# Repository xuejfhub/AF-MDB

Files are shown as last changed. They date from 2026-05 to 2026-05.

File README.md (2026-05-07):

# AF-MDB

AF-MDB (AF Motor Development Board) 是一个基于 STM32H7 的 PMSM/BLDC 电机控制开发板与对拖实验平台，包含硬件原理图、STM32 固件、MATLAB/Simulink 仿真模型和由 Simulink Embedded Coder 生成的 FOC 算法代码。

## 项目图览

<table>
	<tr>
		<td align="center" width="50%">
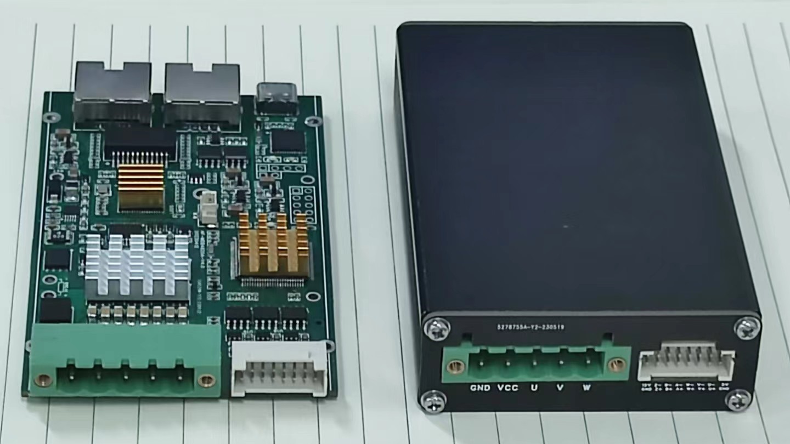
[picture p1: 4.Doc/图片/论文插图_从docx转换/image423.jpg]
驱动器实物照片
			<br>
			<strong>驱动器实物</strong>
		</td>
		<td align="center" width="50%">
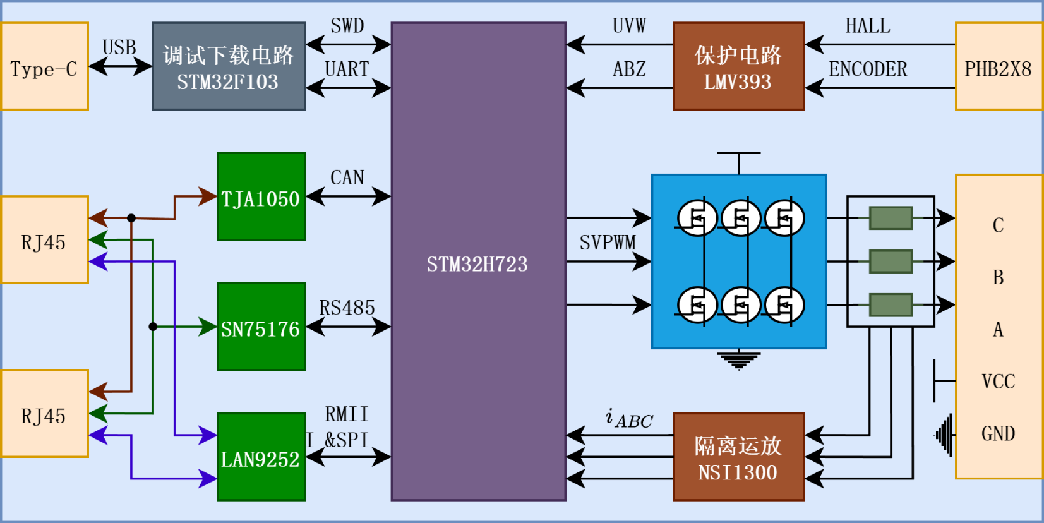
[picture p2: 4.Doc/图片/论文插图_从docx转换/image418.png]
驱动器硬件框图
			<br>
			<strong>硬件设计框图</strong>
		</td>
	</tr>
	<tr>
		<td align="center" width="50%">
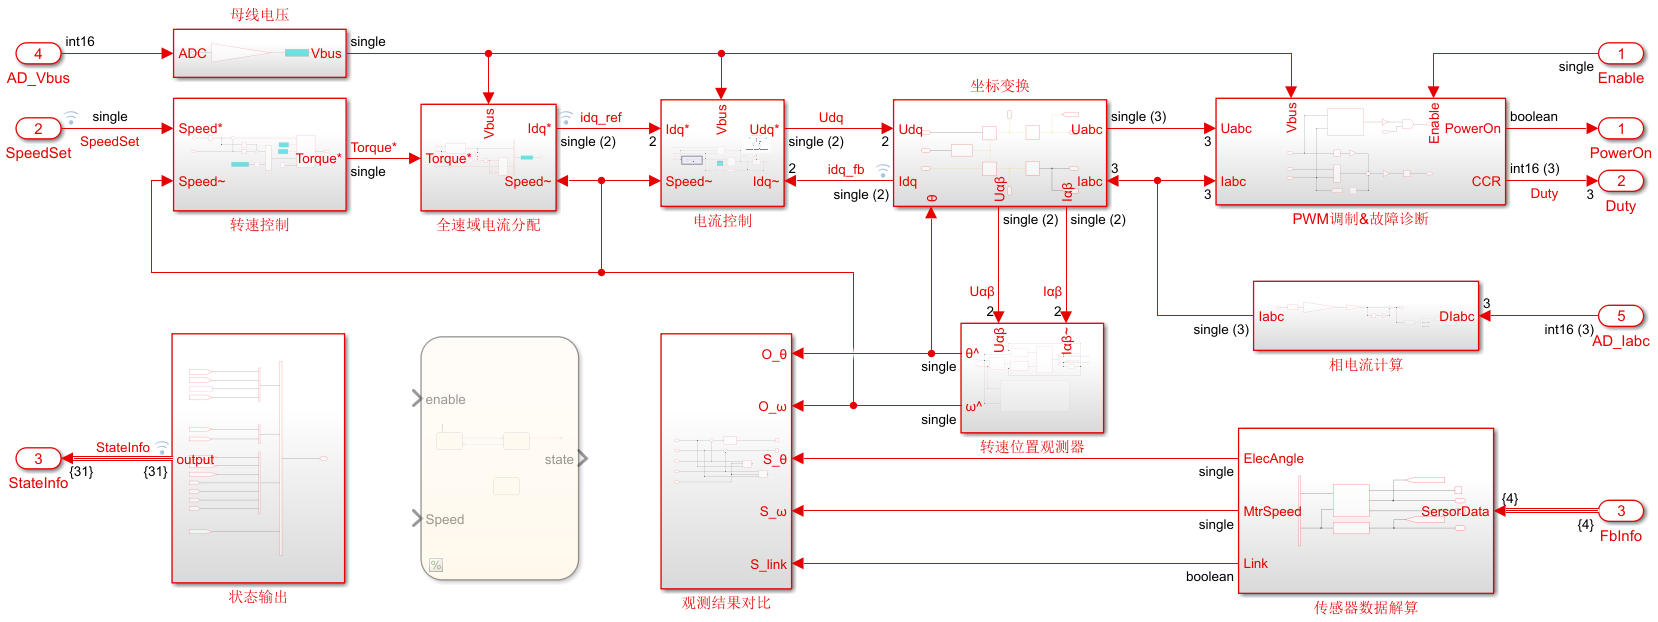
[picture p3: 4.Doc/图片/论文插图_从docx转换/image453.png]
无位置传感器 FOC 控制仿真设计图
			<br>
			<strong>Simulink 控制仿真图</strong>
		</td>
		<td align="center" width="50%">
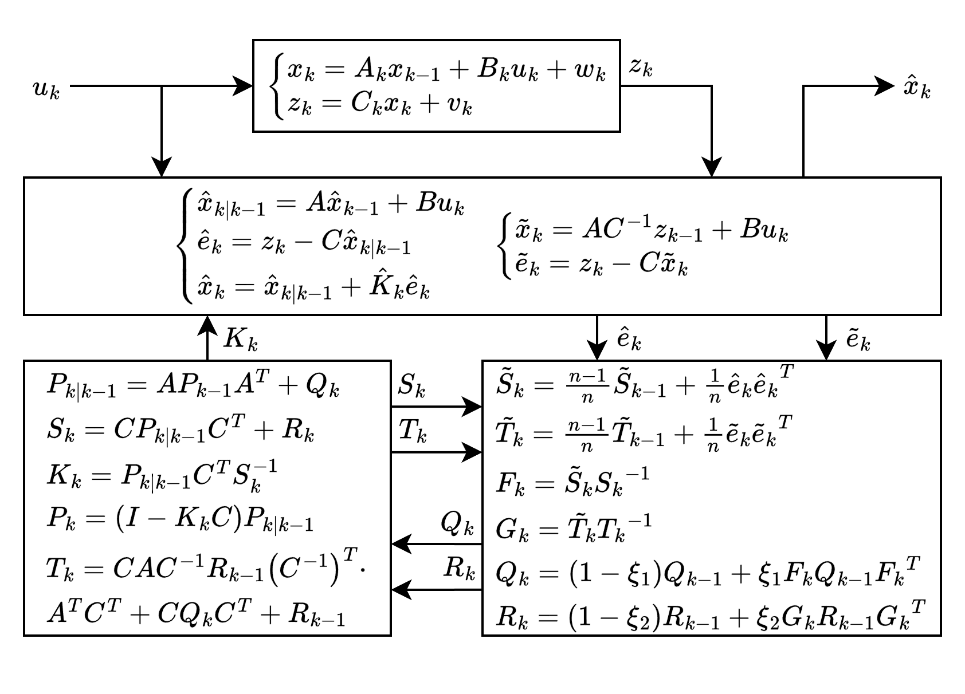
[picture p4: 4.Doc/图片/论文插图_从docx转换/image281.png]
自适应卡尔曼观测器
			<br>
			<strong>自适应卡尔曼观测器</strong>
		</td>
	</tr>
	<tr>
		<td align="center" width="50%">
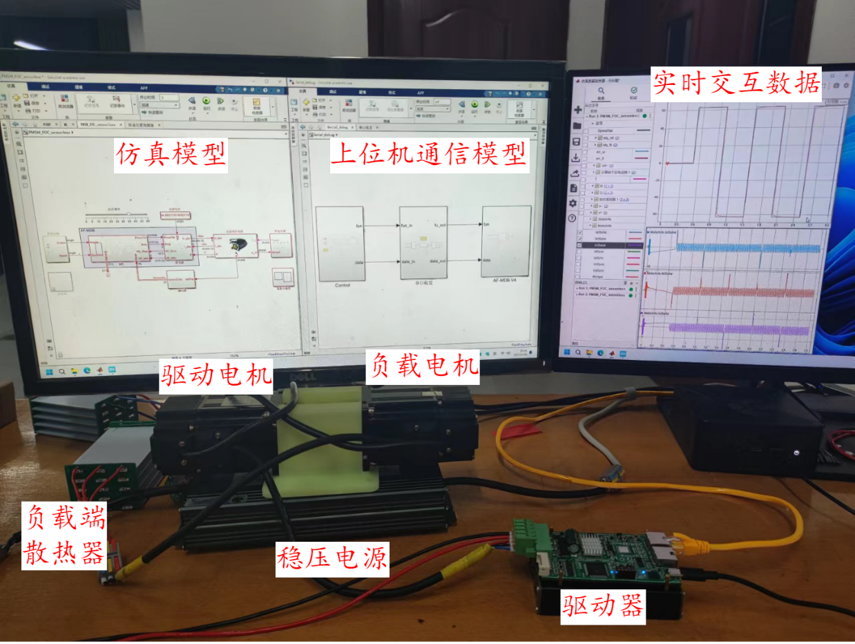
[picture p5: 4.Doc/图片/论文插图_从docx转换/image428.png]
双电机对拖联调平台
			<br>
			<strong>双电机对拖联调平台</strong>
		</td>
		<td align="center" width="50%">
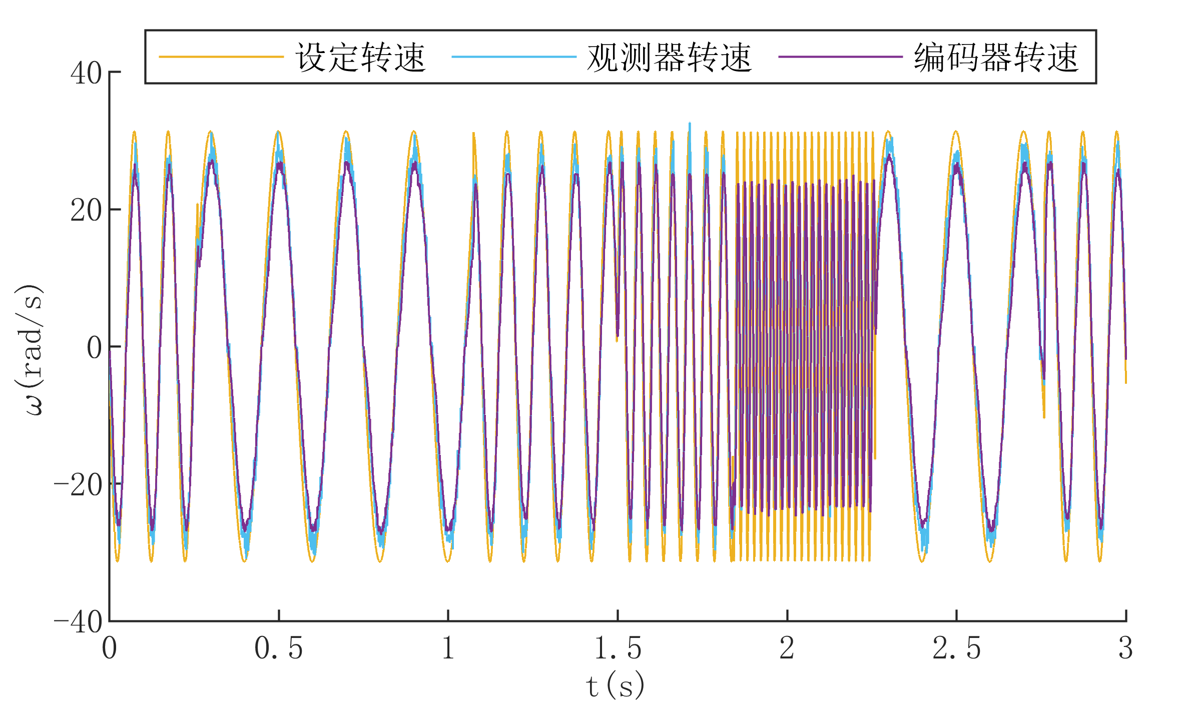
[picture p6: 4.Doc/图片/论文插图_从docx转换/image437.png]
实物转速动态跟踪曲线
			<br>
			<strong>实物转速动态跟踪曲线</strong>
		</td>
	</tr>
</table>

## 算法与实验亮点

AF-MDB 的核心目标是在不使用位置传感器、尽量避免高频注入噪声的情况下，实现 PMSM 全速度范围控制。项目中的两个关键思路是：

- **FAKF 快速自适应卡尔曼观测器**：先由电压、电流计算反电动势，再从反电动势提取带噪声的速度和角度测量值，最后用低阶线性卡尔曼观测器融合机械模型。相比直接对 PMSM 非线性模型做 EKF，FAKF 降低了矩阵运算量，并通过残差、息差自适应调整 `Q/R` 噪声协方差。
- **OAPT 最优电流点跟踪**：把低速角度稳定、d 轴电流损耗和高速电压余量合成为性能指标 $J(i_d, \omega_m, U_{dc})$，在线跟踪 $i_d^{\ast}=\arg\min J$。低速时用正向 d 轴电流帮助角度收敛，高速或欠压时转入弱磁，减少高频注入和策略切换。

实物实验在双电机对拖平台上完成，结果表明：从 5% 额定转速加速到 95% 额定转速用时小于 0.03 s，额定转速下速度波动小于 1%，转速环带宽可达 50 Hz；相比高频注入法，实验中运行噪声降低约 1.86 dB；在 STM32H723 上 FAKF 算法耗时约 28.3 us，比传统 EKF 少约 16.4 us。

## 仓库内容

- `1.Hardware/`：硬件说明、引脚映射、各版本原理图导出文件和必要设计资料。完整在线原理图、PCB 和硬件工程以 OSHWHub 页面为准。
- `2.Software/`：STM32CubeIDE 固件工程。当前主线工程为 `MDB-V4.1`，可直接使用仓库内的 `3.Simulation/FOC_ert_rtw/` 编译，不需要重新生成 Simulink 代码。
- `3.Simulation/`：MATLAB/Simulink 模型、参数脚本、电机参数和驱动参数。主要仿真模型为 `model/Simulation/PMSM_FOC_sensorless.slx`，`model/Simulation/ModelRef/FOC.slx` 用作固件算法引用模型和代码生成入口。
- `4.Doc/`：项目说明、设计文档和研究资料。

## 推荐环境

- STM32CubeIDE 1.19.0：用于导入、配置和编译 `2.Software/MDB-V4.1`。
- STM32CubeMX：随 CubeIDE 使用，用于生成底层外设驱动初始化代码。
- MATLAB/Simulink R2026a：用于打开仿真模型、运行参数脚本，并通过 Embedded Coder 重新生成算法 C 代码。

## 开源范围

当前公开仓库以已发布和可复现的历史版本资料为主。硬件与软件的 V5.0 目录属于本地私有开发资料，不纳入 GitHub 公开仓库；其他版本资料按 `.gitignore` 过滤编译产物、制造输出和本地备份后可推送到云端。

## 快速开始

### 查看硬件

打开 OSHWHub 项目页查看完整硬件工程：

<https://oshwhub.com/xue_jingfei/af-mdb>

Git 仓库中的硬件资料主要用于快速查看原理图、理解接口定义，并与软件和仿真工程对应。若需要打样或修改 PCB，请优先以 OSHWHub 上的最新版工程文件为准。

### 编译固件

1. 安装 STM32CubeIDE 1.19.0。
2. 用 STM32CubeIDE 导入 `2.Software/MDB-V4.1`。
3. 执行 Build Project。

CubeMX 负责底层外设驱动配置和初始化代码生成，FOC 算法代码由 Simulink Embedded Coder 生成。仓库会保留 `3.Simulation/FOC_ert_rtw/`，因此只想编译固件的用户不需要安装 MATLAB/Simulink。若修改 `3.Simulation/model/Simulation/ModelRef/FOC.slx`，则需要重新生成该目录后再编译固件。

### 运行仿真

1. 使用 MATLAB 打开 `3.Simulation/AFMCS.prj`。
2. 运行 `3.Simulation/code/ParameterInit.mlx` 初始化参数。
3. 打开 `3.Simulation/model/Simulation/PMSM_FOC_sensorless.slx` 运行主要控制仿真。
4. 如需重新生成固件算法代码，打开 `3.Simulation/model/Simulation/ModelRef/FOC.slx` 并生成 `FOC_ert_rtw/`。

## 算法说明

`MDB-V4.1` 是当前推荐的主线固件工程。算法模型采用独立引用模型 `3.Simulation/model/Simulation/ModelRef/FOC.slx`，接口和数据类型已按嵌入式代码生成流程配置完成，可直接使用 Embedded Coder 生成 C 语言代码。固件工程直接引用 `3.Simulation/FOC_ert_rtw/` 中的生成代码，并在应用层完成 ADC、编码器、Hall、上位机命令和 PWM 输出之间的适配。

Simulink 算法模型包含作者改进的快速自适应卡尔曼观测器算法和最优电流点跟踪策略，用于 PMSM 全速度范围无传感器控制。建议先阅读 [4.Doc/永磁同步电机低噪声全速度范围无传感器控制研究.md](4.Doc/永磁同步电机低噪声全速度范围无传感器控制研究.md) 了解项目相关的核心思想；完整算法原理、推导和实验结果请查阅论文《永磁同步电机低噪声全速度范围无传感器控制研究》。

## 安全说明

本项目涉及电机驱动、功率电子、电流采样和高速 PWM 控制。复现前请确认供电电压、电流限制、母线电容耐压、过流/过压/欠压保护、散热和急停措施。首次上电建议使用限流电源，并在接入电机前验证采样零点、PWM 死区和保护逻辑。

## 引用

本项目的控制算法来自论文《永磁同步电机低噪声全速度范围无传感器控制研究》。精简版见 [4.Doc/永磁同步电机低噪声全速度范围无传感器控制研究.md](4.Doc/永磁同步电机低噪声全速度范围无传感器控制研究.md)。

如果本项目对你的研究或开发有帮助，可以参考原论文：

> 《永磁同步电机低噪声全速度范围无传感器控制研究》
> DOI: `10.27759/d.cnki.ggxgx.2024.000640`

完整硬件开源页面：<https://oshwhub.com/xue_jingfei/af-mdb>

## 许可证

请以仓库根目录 `LICENSE` 文件和 OSHWHub 项目页面标注为准。若当前副本未包含明确许可证，请在复用或再发布前联系作者确认授权范围。

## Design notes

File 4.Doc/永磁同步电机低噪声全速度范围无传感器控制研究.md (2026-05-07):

# 永磁同步电机低噪声全速度范围无传感器控制研究：项目技术速览

> 本文档是面向 AF-MDB 项目读者整理的技术说明，重点保留第 3、4、5 章中与项目实现相关的创新思想、核心公式、框图和实验结论。
>
> 原论文中的封面、声明、目录、学校培养信息、绪论综述、参考文献和致谢已删去。完整理论推导、公式编号、文献来源和实验细节请查阅原论文《永磁同步电机低噪声全速度范围无传感器控制研究》，DOI: `10.27759/d.cnki.ggxgx.2024.000640`。

## 阅读线索

这份速览不再按论文格式展开，而是按项目读者最关心的顺序组织：

1. 先理解 PMSM 无传感器控制为什么难：低速反电动势弱、高速电压受限、高频注入有噪声。
2. 再看第 3 章的 FAKF：如何把传统 EKF 拆成“非线性测量提取 + 低阶线性卡尔曼观测”。
3. 再看第 4 章的 OAPT：如何用 d 轴电流同时处理低速稳定、高速弱磁和电池欠压。
4. 最后看第 5 章的工程验证：硬件、软件、联调平台、实物转速跟踪、噪声和运行时间。

## 项目要解决的问题

PMSM 无传感器控制希望不依赖编码器或位置传感器，直接通过电压、电流和电机模型估计转子位置与转速，再完成 FOC 闭环控制。这样可以降低成本、减少线束、提升系统可靠性，但工程上会遇到几个矛盾：

- **低速和零速难**：反电动势幅值随转速下降而变小，模型观测器很难得到可靠角度。
- **高速电压受限**：转速升高后反电动势增大，母线电压不足时 q 轴电压余量变小，转矩能力下降。
- **高频注入有噪声**：传统全速域方案常在低速使用高频注入，中高速切换到观测器法，但高频电压会带来明显电磁声。
- **切换策略复杂**：两种估计方法之间需要融合、切换或权重调度，边界稳定性和参数调试都比较麻烦。
- **嵌入式算力有限**：20 kHz 控制频率下单周期只有 50 us 左右，ADC、观测器、FOC 和 PWM 更新都要在一个周期内完成。

AF-MDB 的算法主线可以概括为：**用快速自适应卡尔曼观测器 FAKF 提高位置/速度估计质量，用最优电流点跟踪 OAPT 改善观测器在零低速和弱磁区的工作条件，从而减少对高频注入和多策略切换的依赖。**

## 第 3 章：FAKF 快速自适应卡尔曼观测器

### 创新思想

传统 EKF 通常直接对 PMSM 的非线性状态方程做局部线性化，状态维度高，雅可比矩阵复杂，实时运行成本较高，而且过程噪声 `Q`、测量噪声 `R` 对调参非常敏感。

FAKF 的关键改动是把非线性环节和卡尔曼滤波环节分开：

1. 先由采样电压、电流计算反电动势。
2. 再由反电动势提取带噪声的角度和速度测量值。
3. 最后只对速度、角度构成的低阶线性系统做卡尔曼融合。
4. 用残差和息差在线估计噪声协方差，使 `Q`、`R` 能随工况变化自适应调整。

### 非线性测量提取

在静止坐标系下，可先由电压方程提取反电动势。工程离散形式可以理解为：

$$
\begin{aligned}
e_{\alpha}(k) &= u_{\alpha}(k) - R_s i_{\alpha}(k) - L_s \frac{i_{\alpha}(k)-i_{\alpha}(k-1)}{T_s} \\
e_{\beta}(k) &= u_{\beta}(k) - R_s i_{\beta}(k) - L_s \frac{i_{\beta}(k)-i_{\beta}(k-1)}{T_s}
\end{aligned}
$$

对表贴式 PMSM，反电动势与电角度、转速近似满足：

$$
\begin{aligned}
e_{\alpha} &= -\omega_e \psi_f \sin\theta_e \\
e_{\beta} &= \omega_e \psi_f \cos\theta_e
\end{aligned}
$$

因此可以从反电动势中得到测量角度和速度：

$$
\begin{aligned}
θ_{e,z} &= \operatorname{atan2}(-e_{\alpha}, e_{\beta}) \\
|\omega_{e,z}| &= \frac{\sqrt{e_{\alpha}^{2}+e_{\beta}^{2}}}{\psi_f}
\end{aligned}
$$

由于反电动势在低速时很弱，这一步得到的是“带噪声的测量值”，不是最终估计值。FAKF 的作用就是把这些测量值和机械运动模型融合起来。

电磁转矩作为观测器输入，常用表达为：

$$
T_e = 1.5p\left[\psi_f i_q + (L_d-L_q)i_d i_q\right]
$$

对于表贴式 PMSM，`L_d` 与 `L_q` 接近，上式常简化为：

$$
T_e \approx 1.5p\psi_f i_q
$$

### 低阶线性观测器

FAKF 只把机械速度和电角度作为核心状态：

$$
\begin{aligned}
x_k &= [\omega_m,\ \theta_e]^T \\
u_k &= T_e \\
z_k &= [\omega_{m,z},\ \theta_{e,z}]^T
\end{aligned}
$$

离散机械模型可写成线性状态空间形式：

$$
\begin{aligned}
x_k &= A x_{k-1} + B u_k + w_k \\
z_k &= H x_k + v_k
\end{aligned}
$$

其中 `w_k` 是过程噪声，主要吸收负载扰动、模型不准和未建模动态；`v_k` 是测量噪声，主要来自反电动势提取、电流采样和数值微分。相比传统 4 阶非线性 EKF，这个观测器的矩阵维度更小，状态转移矩阵更简单，更适合放进 STM32H7 的高速控制周期。

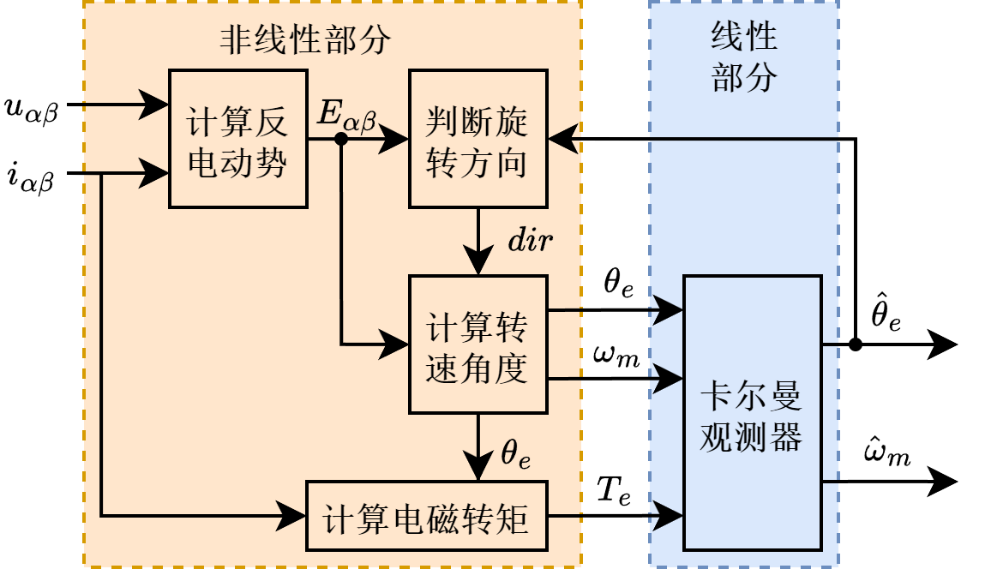
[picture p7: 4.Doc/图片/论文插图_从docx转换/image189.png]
FAKF 观测器结构


### 卡尔曼更新过程

FAKF 的滤波核心仍然遵循标准离散卡尔曼预测与校正：

$$
\begin{aligned}
x_k^- &= A x_{k-1} + B u_k \\
P_k^- &= A P_{k-1} A^T + Q_k \\
K_k &= P_k^- H^T\left(H P_k^- H^T + R_k\right)^{-1} \\
x_k &= x_k^- + K_k\left(z_k - Hx_k^-\right) \\
P_k &= \left(I-K_kH\right)P_k^-
\end{aligned}
$$

这里 `K_k` 是卡尔曼增益，`P_k` 是估计协方差。传统 EKF 的难点在于 `Q`、`R` 难以固定整定：转速、采样噪声、负载扰动变化后，原先好用的噪声矩阵可能变得不匹配。

### Q/R 自适应思想

论文中引入两个误差信号：

$$
\begin{aligned}
r_k &= z_k - Hx_k^- \\
d_k &= z_k - z_k^-
\end{aligned}
$$

其中 $r_k$ 为残差，表示测量值与当前预测值之间的偏差；$d_k$ 为息差，表示新的测量值与基于上一时刻信息预测测量值之间的偏差。

然后在线估计残差和息差的协方差：

$$
\begin{aligned}
C_r(k) &= \operatorname{cov}(r_k) \\
C_d(k) &= \operatorname{cov}(d_k)
\end{aligned}
$$

直觉上：

- 残差的统计强度反映“测量噪声和预测不一致”的程度。
- 息差的统计强度可以帮助区分过程噪声和测量噪声。
- 当估计协方差与理论协方差不匹配时，说明当前 `Q_k` 或 `R_k` 需要调整。

为了避免直接做矩阵减法导致协方差矩阵失去正定性，论文采用合同变换思想修正 `Q`、`R`。工程上可以理解为：

$$
\begin{aligned}
Q_{k+1} &= \operatorname{adapt}\left(Q_k, C_d, C_{d,\mathrm{theory}}\right) \\
R_{k+1} &= \operatorname{adapt}\left(R_k, C_r, C_{r,\mathrm{theory}}\right)
\end{aligned}
$$

其中自适应律带有收敛系数，用来控制噪声矩阵调整速度。这样 FAKF 不必长期依赖一组固定噪声参数，能够随转速变化、扰动和采样噪声变化调整滤波权重。

自适应卡尔曼观测器信号流

### 最终效果

FAKF 的效果主要体现在三点：

- 在全速阶跃、低速突加负载、高速突加负载、正弦加减速等仿真中，速度和角度能较好跟随真实值。
- 与传统 EKF 相比，FAKF 避免了高阶非线性矩阵运算，降低了实时计算成本。
- 自适应噪声矩阵使观测器在不同转速段能保持更稳定的误差特性。

## 第 4 章：OAPT 最优电流点跟踪

### 创新思想

FAKF 虽然降低了 EKF 的计算量并提高了中高速观测质量，但接近零速时反电动势仍然趋近于零，仅靠反电动势观测很容易角度不收敛。传统办法是低速高频注入，中高速观测器法，再做切换。OAPT 的思路不同：**它不额外估计角度，而是通过 d 轴电流改变电机工作点，让同一个观测器在零低速、高速和欠压时都更容易工作。**

### d 轴电流的三个作用

在表贴式 PMSM 中，d 轴电流几乎不产生主要转矩，但它会影响三个关键指标：

1. **角度稳定性**：低速时正向 d 轴电流能让角度误差形成更有利的负反馈。
2. **效率与发热**：d 轴电流越大，铜损和无功功率越大。
3. **电压余量**：高速或欠压时负向 d 轴电流可弱磁，降低反电动势，为 q 轴控制保留电压空间。

在论文采用的符号约定下，角度误差 $\Delta\theta$ 存在时，d 轴电流会产生一个与误差相关的转矩项，可概括为：

$$
T_d \approx 1.5p\psi_f i_d \sin(\Delta\theta)
$$

当 `i_d` 的方向选择合适时，这个转矩项会帮助角度误差收敛；方向相反时，可能形成正反馈并放大误差。这也是 OAPT 在低速选择正向 d 轴电流的核心原因。

### 综合性能指标

OAPT 将“低速稳定、效率、高速电压余量”统一成一个性能指标函数。工程理解可写为：

$$
J(i_d, \omega_m, U_{dc}) = L J_{\mathrm{stable}} + M J_{\mathrm{loss}} + N J_{\mathrm{voltage}}
$$

其中：

- `J_stable` 描述低速角度稳定性需求。
- `J_loss` 描述 d 轴电流带来的发热和无功功率损失。
- `J_voltage` 描述高速或欠压时的电压余量。
- `L`、`M`、`N` 是权重，可根据应用偏向低速稳定、效率或高速性能。

最终控制目标是找到当前转速和母线电压下的最优 d 轴电流：

$$
i_d^{\ast} = \arg\min_{i_d} J(i_d, \omega_m, U_{dc})
$$

论文没有把这个问题做成重计算量的解析求解，而是使用梯度下降思想在线跟踪最优点：

$$
\frac{\partial J}{\partial i_d} \approx \frac{J(i_d + \Delta i, \omega_m, U_{dc}) - J(i_d, \omega_m, U_{dc})}{\Delta i}
$$

$$
i_d^{\ast}(k+1)=\operatorname{sat}\left[i_d^{\ast}(k)-\eta\frac{\partial J}{\partial i_d}\right]
$$

`eta` 是学习率，`sat[]` 用来限制电流范围。这样算法可以在控制周期内轻量运行，不需要复杂求导或查大表。

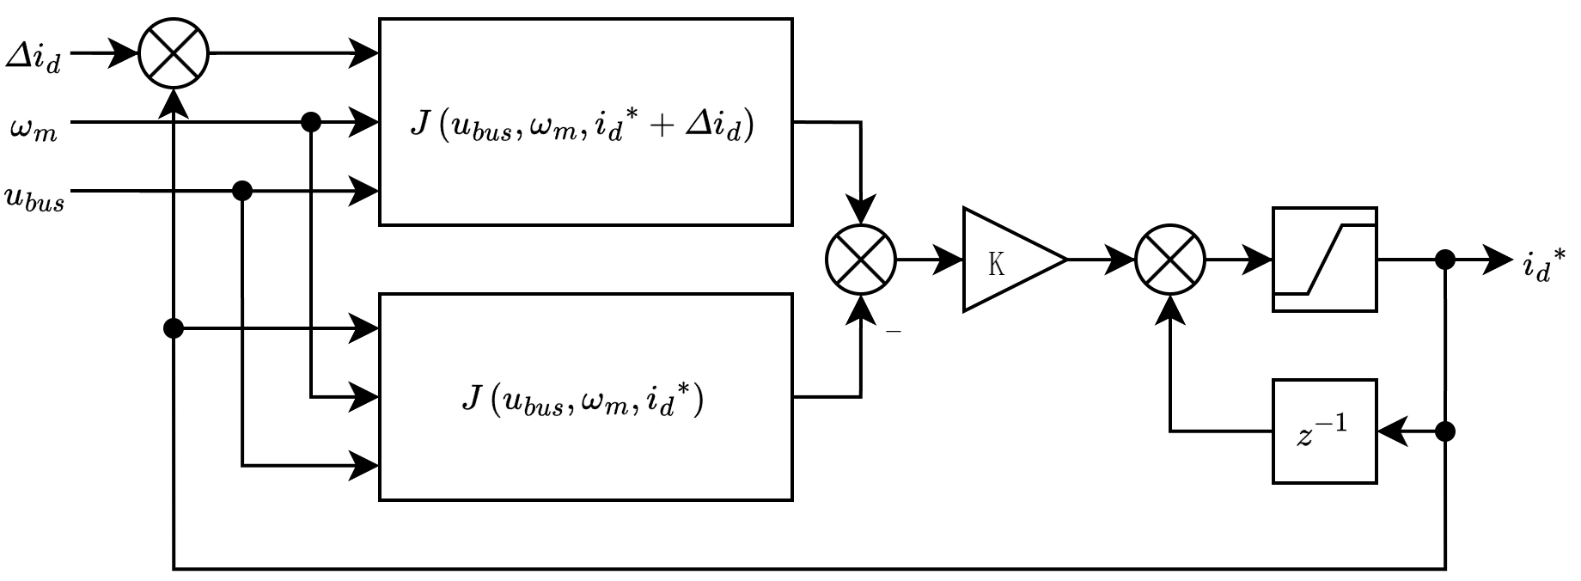
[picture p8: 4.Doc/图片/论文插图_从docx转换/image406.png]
最优电流点跟踪框图


### FAKF + OAPT 的组合方式

FAKF 和 OAPT 位于控制系统的不同位置：

- FAKF 负责估计转速和角度。
- OAPT 负责给出当前工况下更合适的 d 轴电流目标。
- 两者同时工作，不需要像“高频注入 + 观测器法”那样设计切换边界。

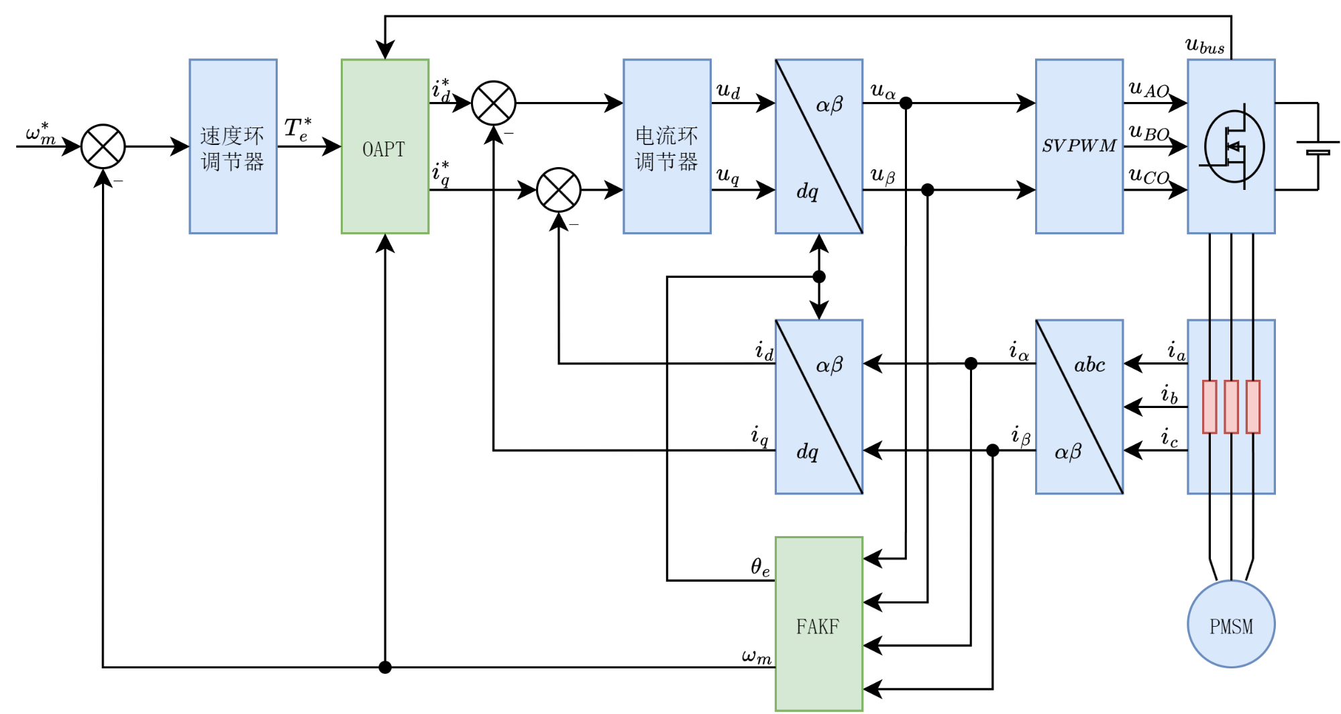
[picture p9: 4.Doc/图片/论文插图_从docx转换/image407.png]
FAKF 与 OAPT 结合后的全速度范围控制结构


### 最终效果

OAPT 的意义不是单纯“弱磁”，而是把低速启动、高速弱磁和欠压补偿放到同一套电流分配逻辑里：

- 零低速时通过正向 d 轴电流改善角度收敛，减少启动反转。
- 中速时尽量减小无效 d 轴电流，兼顾效率。
- 高速或母线电压不足时自动偏向弱磁，保证 q 轴电压余量。
- 不使用高频注入，因此可避免高频注入带来的尖锐运行噪声。

## 第 5 章：实验平台与实物验证

### 硬件平台

论文实验平台围绕 STM32H7 系列主控设计，硬件包含电源保护与 DCDC、MCU 最小系统、下载调试、三相逆变器、电流采样、编码器/Hall 接口和通信接口等模块。驱动器参数包括 20 kHz 控制频率、ADC 采样、电流采样和 PWM 死区配置等，目标是让算法能在真实功率驱动条件下闭环运行。

驱动器硬件设计方案

驱动器实物照片

### 软件与仿真

软件按层次划分为底层驱动、算法层和应用层。Simulink/Embedded Coder 负责生成 FOC、FAKF、OAPT 等算法代码；STM32CubeIDE 工程负责外设初始化、中断调度、ADC/PWM/通信和保护逻辑。

无位置传感器 FOC 控制仿真设计图

### 实物联调平台

实验采用双电机对拖平台：一台电机作为被控电机，另一台电机作为负载电机，通过负载电阻模拟风机、泵类负载特性。这样可以验证算法在带载、正反转、低速、高速和动态变速下的实际表现。

双电机对拖实验平台

### 实物实验结果

论文中重点验证了四类结果：

| 测试项目 | 结果摘要 |
| --- | --- |
| 高低速正反转带载 | 从 5% 额定转速加速到 95% 额定转速，用时小于 0.03 s；稳态速度误差小于 1%。 |
| 动态转速跟踪 | 50 Hz 转速激励下仍能稳定跟随，角度误差保持在可收敛范围内。 |
| 运行噪声 | 相比高频注入法，实验中运行噪声平均降低约 1.86 dB。 |
| 算法耗时 | STM32H723 上 FAKF 总耗时约 28.3 us，传统 EKF 约 44.7 us，减少约 16.4 us。 |

实物转速动态跟踪曲线

### 工程结论

综合仿真和实物实验，FAKF + OAPT 的价值主要是：

1. 在不使用位置传感器的情况下覆盖零速、低速、中高速、正反转和带载工况。
2. 用 OAPT 替代高频注入的低速稳定作用，降低运行噪声。
3. 用低阶观测器和自适应噪声矩阵降低 EKF 的计算压力和调参压力。
4. 在 STM32H7 + 20 kHz 控制频率下保留实时裕度，便于工程移植。

## 与 AF-MDB 仓库的关系

| 目标 | 路径 | 说明 |
| --- | --- | --- |
| 固件工程 | `2.Software/MDB-V4.1/` | 当前推荐的 STM32CubeIDE 主线工程。 |
| 仿真工程 | `3.Simulation/AFMCS.prj` | MATLAB 项目入口。 |
| 控制仿真 | `3.Simulation/model/Simulation/PMSM_FOC_sensorless.slx` | PMSM 无传感器 FOC 仿真模型。 |
| 代码生成入口 | `3.Simulation/model/Simulation/ModelRef/FOC.slx` | 用于 Embedded Coder 生成嵌入式算法代码。 |
| 生成代码 | `3.Simulation/FOC_ert_rtw/` | 固件工程直接引用的算法 C 代码。 |
| 硬件资料 | `1.Hardware/` | 原理图导出、引脚映射和历史版本硬件资料。 |

如果你想复现或继续开发，建议先从 `3.Simulation/model/Simulation/ModelRef/FOC.slx` 和 `3.Simulation/model/Simulation/PMSM_FOC_sensorless.slx` 理解算法，再看 `2.Software/MDB-V4.1/` 中如何把生成代码接入 ADC、PWM、编码器、Hall 和通信任务。

## 适用边界与注意事项

- OAPT 会在低速阶段引入 d 轴电流来换取角度稳定性，因此效率不是唯一目标；若目标是极限低功耗，需要重新调整性能指标权重。
- 文档中的公式采用工程化表达，省略了论文中的部分符号定义、严格推导和稳定性证明；完整推导请查阅原论文。
- 实物结果与电机参数、母线电压、电流采样噪声、控制频率、机械负载和保护策略有关，移植到其他电机前需要重新整定和验证。
- 本项目涉及功率电子和高速电机控制，首次上电必须限流，并确认采样零点、PWM 死区、保护阈值和急停措施。

## 引用

如果这份项目资料或算法思路对你的研究和开发有帮助，可以引用原论文：

> 《永磁同步电机低噪声全速度范围无传感器控制研究》
> DOI: `10.27759/d.cnki.ggxgx.2024.000640`

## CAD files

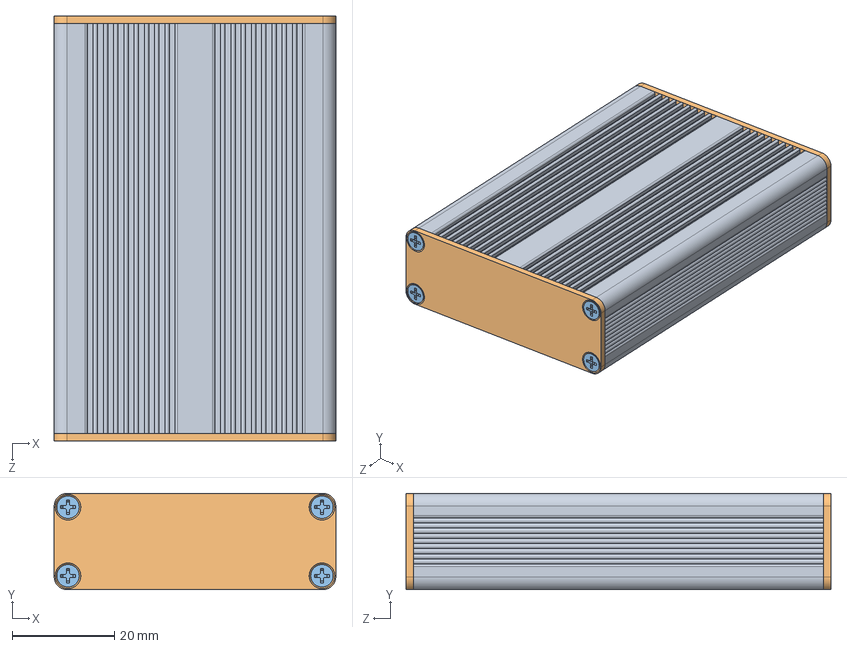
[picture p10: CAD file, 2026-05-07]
1.Hardware/外壳3D文件/V3外壳(J03-55-19)/YG-J03A-0000-000.step
55.0 x 18.8 x 83.0 mm
YG-J03A-0000-001
YG-J03A-0000-002 x 2
GB-T-819.1-2000-C-NI-M2.5X6 x 8

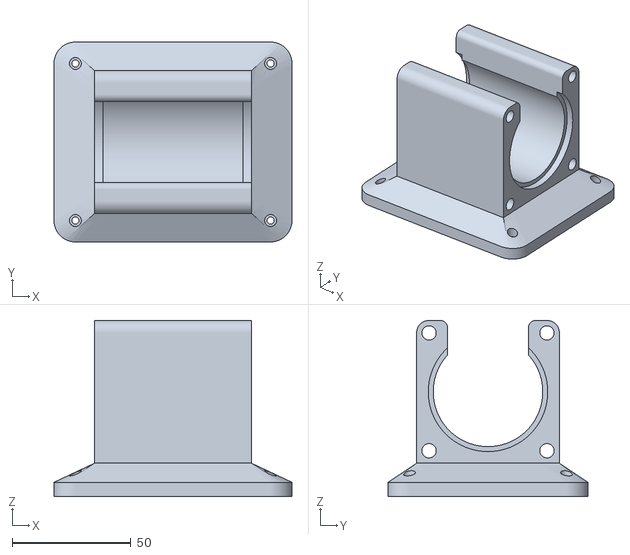
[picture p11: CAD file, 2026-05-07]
1.Hardware/电机支架/60电机对拖支架-支架.obj
100.0 x 84.0 x 74.0

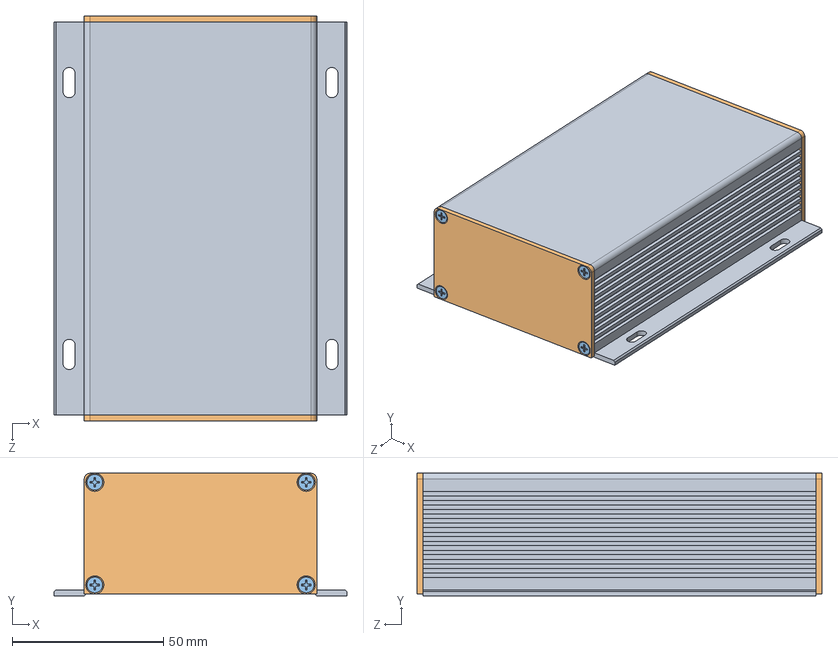
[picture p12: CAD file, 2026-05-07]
1.Hardware/外壳3D文件/V4外壳(J26-97-40.5）/YG-J26A-0000-000.step
97.0 x 40.6 x 134.0 mm
YG-J26A-0000-001
YG-J26A-0000-002 x 2
GB-T-819.1-2000-C-NI-M3X6 x 8

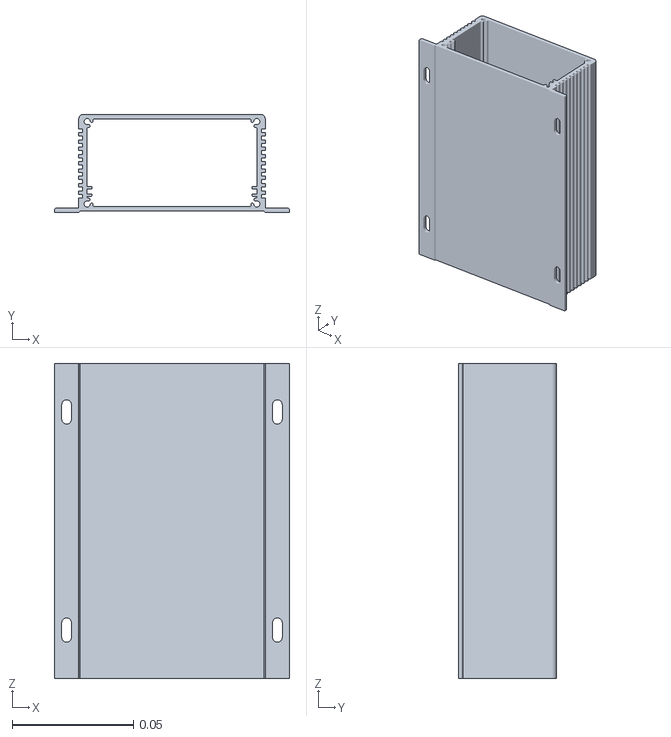
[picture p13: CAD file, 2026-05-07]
1.Hardware/外壳3D文件/V4外壳(J26-97-40.5）/J26-97-40.5-body.obj
0.097 x 0.0406 x 0.13

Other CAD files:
1.Hardware/外壳3D文件/V4外壳(J26-97-40.5）/YG-J26A-0000-001.dwg
1.Hardware/外壳3D文件/V3外壳(J03-55-19)/YG-J03A-0000-002.dwg
1.Hardware/电机支架/60电机对拖支架.FCStd
1.Hardware/外壳3D文件/V3外壳(J03-55-19)/YG-J03A-0000-001.dwg
1.Hardware/外壳3D文件/V4外壳(J26-97-40.5）/YG-J26A-0000-002.dwg
1.Hardware/外壳3D文件/V3外壳(J03-55-19)/YG-J03A-0000-000.dwg
1.Hardware/外壳3D文件/V4外壳(J26-97-40.5）/YG-J26A-0000-000.dwg

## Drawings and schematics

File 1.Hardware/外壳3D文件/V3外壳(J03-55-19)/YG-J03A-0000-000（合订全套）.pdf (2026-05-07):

1

2

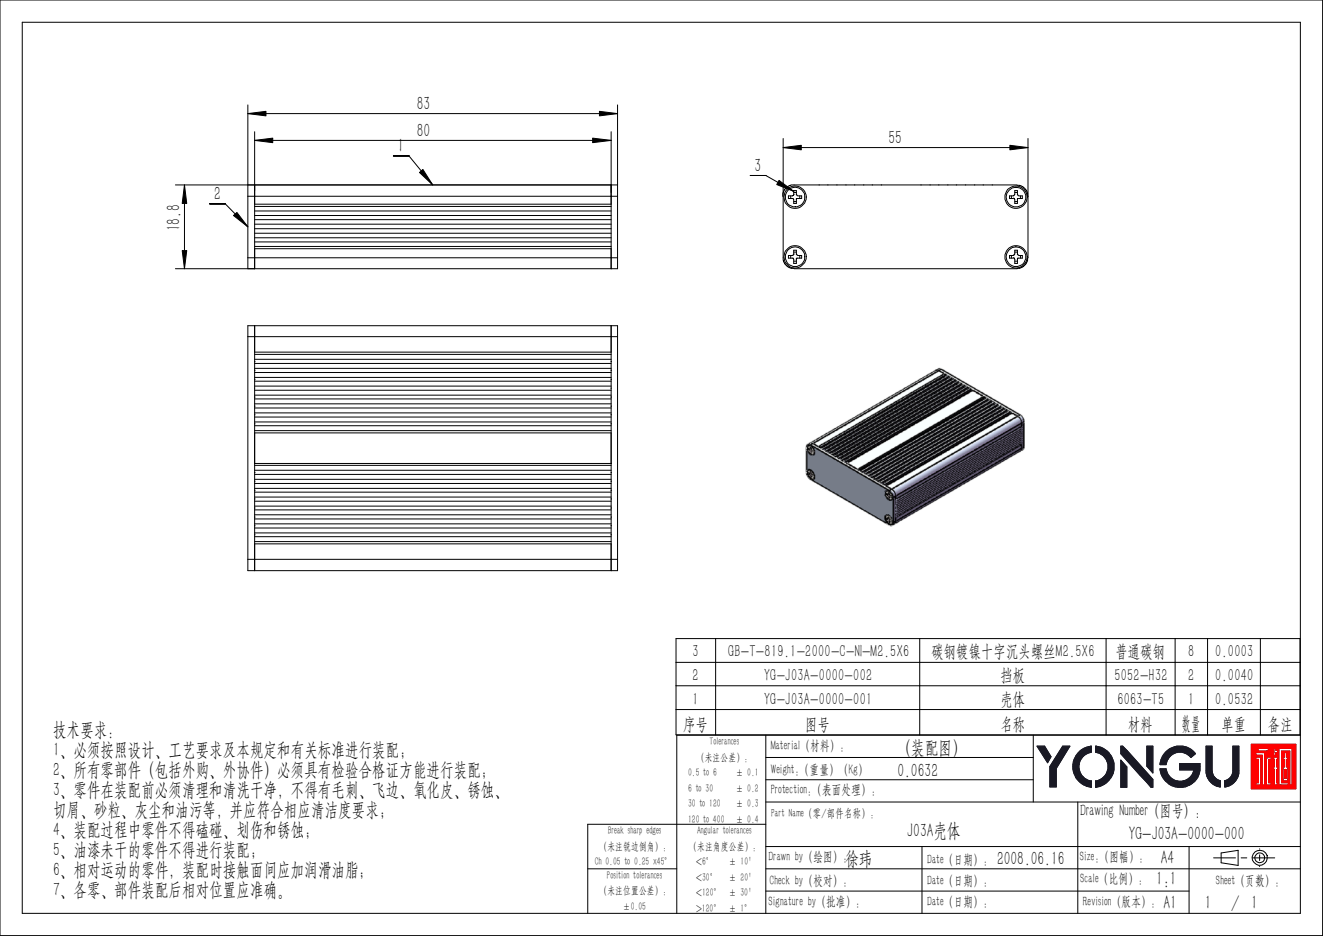
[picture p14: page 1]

3 | GB-T-819.1-2000-C-NI-M2.5X6 | 碳钢镀镍十字沉头螺丝M2.5X6 | 普通碳钢 | 8 | 0.0003
2 | YG-J03A-0000-002 | 挡板 | 5052-H32 | 2 | 0.0040
1 | YG-J03A-0000-001 | 壳体 | 6063-T5 | 1 | 0.0532
序号 | 图号 | 名称 | 材料 | 数量 | 单重 | 备注
Tolerances （未注公差）： 0.5 to 6 ± 0.1 6 to 30 ± 0.2 30 to 120 ± 0.3 120 to 400 ± 0.4 | Material（材料）: （装配图）

技术要求：
1、必须按照设计、工艺要求及本规定和有关标准进行装配；
2、所有零部件（包括外购、外协件）必须具有检验合格证方能进行装配；
3、零件在装配前必须清理和清洗干净，不得有毛刺、飞边、氧化皮、锈蚀、
切屑、砂粒、灰尘和油污等，并应符合相应清洁度要求；
4、装配过程中零件不得磕碰、划伤和锈蚀；
5、油漆未干的零件不得进行装配；
6、相对运动的零件，装配时接触面间应加润滑油脂；
7、各零、部件装配后相对位置应准确。

Weight:（重量）（Kg）
Protection:（表面处理）：

Part Name（零/部件名称）: J03A壳体 | Drawing Number（图号）: YG-J03A-0000-000

Break sharp edges （未注锐边倒角）： Ch 0.05 to 0.25 x45° | Angular tolerances （未注角度公差）： ± 10' <30° ± 20' | Drawn by（绘图）: <6°

徐玮 | 2008.06.16 Date（日期）： | Size:（图幅）： A4

Position tolerances （未注位置公差）： ±0.05 | | Check by（校对）: | Scale（比例）： | Sheet（页数）： /

Signature by（批准）: | A1 Revision（版本）：

A

55

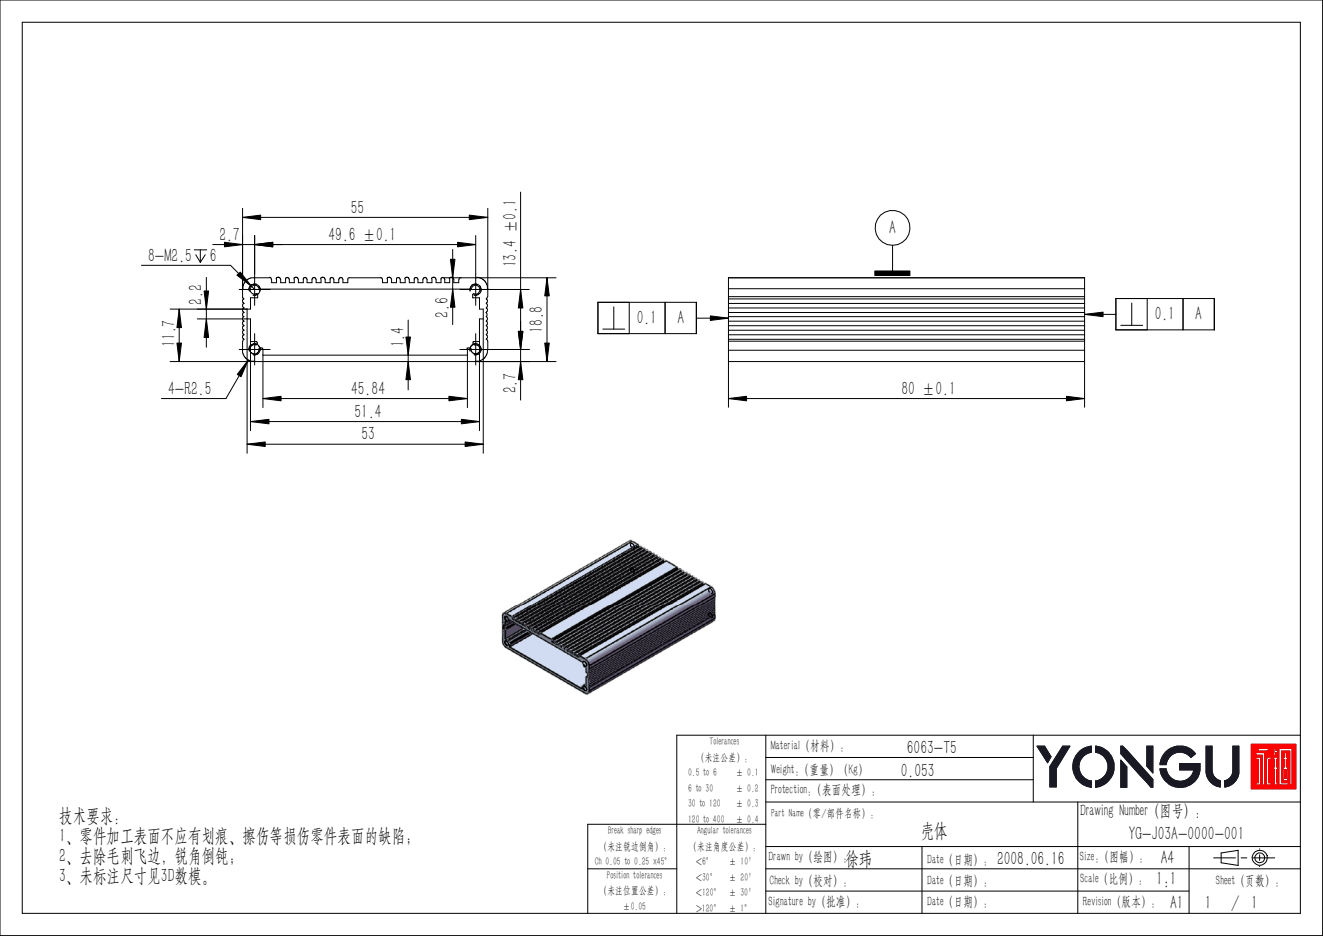
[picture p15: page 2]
Tolerances （未注公差）：; 技术要求： 1、零件加工表面不应有划痕、擦伤等损伤零件表面的缺陷； 2、去除毛刺飞边，锐角倒钝；; 3、未标注尺寸见3D数模。 ¹¹.7

Material（材料）:
Weight:（重量）（Kg）
Protection:（表面处理）：

Part Name（零/部件名称）: 壳体 | Drawing Number（图号）: YG-J03A-0000-001

Break sharp edges （未注锐边倒角）： | Angular tolerances （未注角度公差）： ± 10' | Drawn by（绘图）: <6°

徐玮 | 2008.06.16 | Size:（图幅）： A4

1.5

55

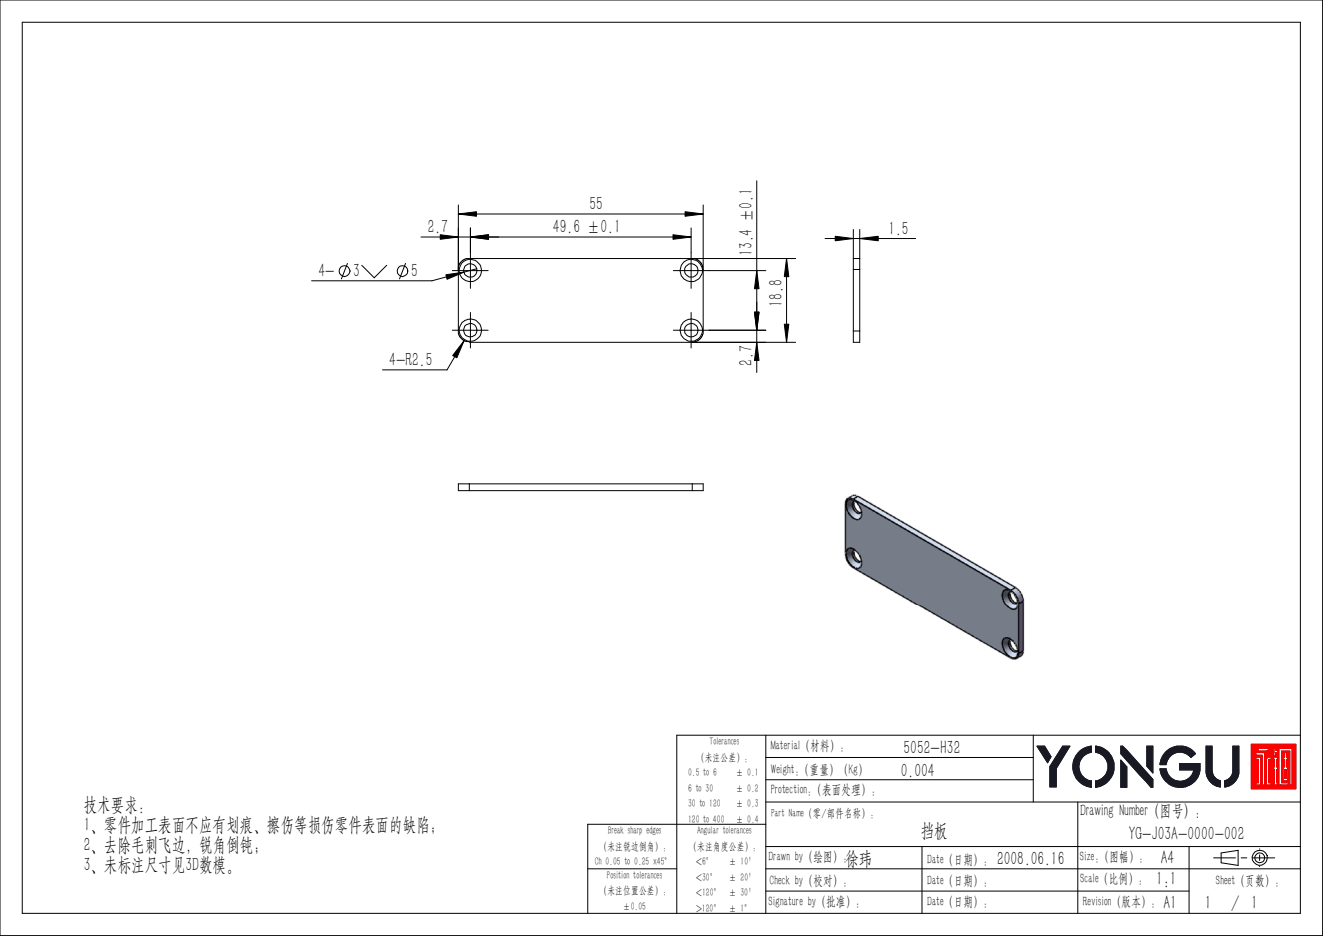
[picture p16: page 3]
Tolerances （未注公差）：; 技术要求： 1、零件加工表面不应有划痕、擦伤等损伤零件表面的缺陷； 2、去除毛刺飞边，锐角倒钝； 3、未标注尺寸见3D数模。

Material（材料）:
Weight:（重量）（Kg）
Protection:（表面处理）：

Part Name（零/部件名称）: 挡板 | Drawing Number（图号）: YG-J03A-0000-002

Break sharp edges （未注锐边倒角）： | Angular tolerances （未注角度公差）： ± 10' | Drawn by（绘图）: <6°

徐玮 | 2008.06.16 | Size:（图幅）： A4

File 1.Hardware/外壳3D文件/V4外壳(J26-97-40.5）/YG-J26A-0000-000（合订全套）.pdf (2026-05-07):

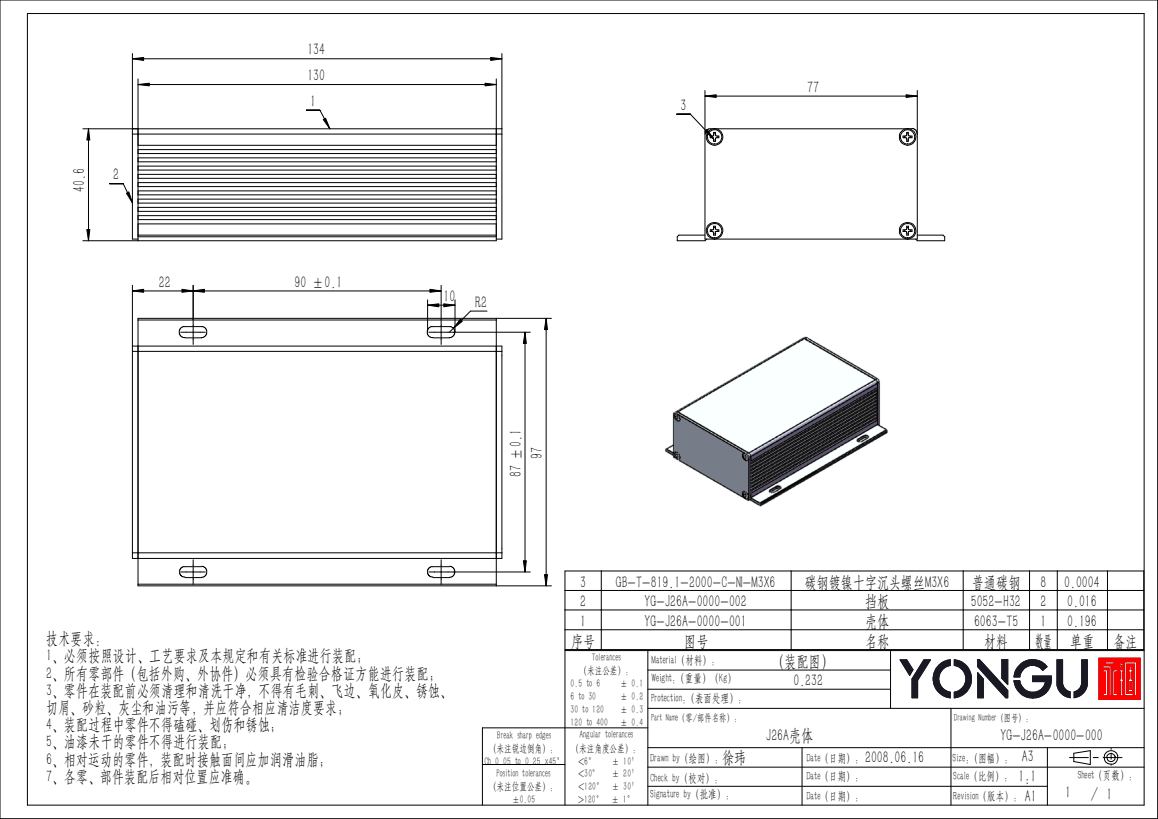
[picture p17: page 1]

3 | GB-T-819.1-2000-C-NI-M3X6 | 碳钢镀镍十字沉头螺丝M3X6 | 普通碳钢 | 8 | 0.0004
2 | YG-J26A-0000-002 | 挡板 | 5052-H32 | 2 | 0.016
1 | YG-J26A-0000-001 | 壳体 | 6063-T5 | 1 | 0.196
序号 | 图号 | 名称 | 材料 | 数量 | 单重 | 备注
（未注公差）： 0.5 to 6 ± 0.1 6 to 30 ± 0.2 30 to 120 ± 0.3 120 to 400 ± 0.4 | Material（材料）: Tolerances （装配图）

技术要求：
1、必须按照设计、工艺要求及本规定和有关标准进行装配；
2、所有零部件（包括外购、外协件）必须具有检验合格证方能进行装配；
3、零件在装配前必须清理和清洗干净，不得有毛刺、飞边、氧化皮、锈蚀、
切屑、砂粒、灰尘和油污等，并应符合相应清洁度要求；
4、装配过程中零件不得磕碰、划伤和锈蚀；
5、油漆未干的零件不得进行装配；
6、相对运动的零件，装配时接触面间应加润滑油脂；
7、各零、部件装配后相对位置应准确。

Weight:（重量）（Kg）
Protection:（表面处理）：

Part Name（零/部件名称）: J26A壳体 | Drawing Number（图号）: YG-J26A-0000-000

Break sharp edges （未注锐边倒角）： Ch 0.05 to 0.25 x45° | Angular tolerances （未注角度公差）： >120° ± 1°

Drawn by（绘图）: 徐玮 | Date（日期）： 2008.06.16 | A3 Size:（图幅）：

Position tolerances （未注位置公差）： ±0.05 | | Check by（校对）: | Scale（比例）： | Sheet（页数）：

Signature by（批准）: | A1 <120° ± 30' Revision（版本）：

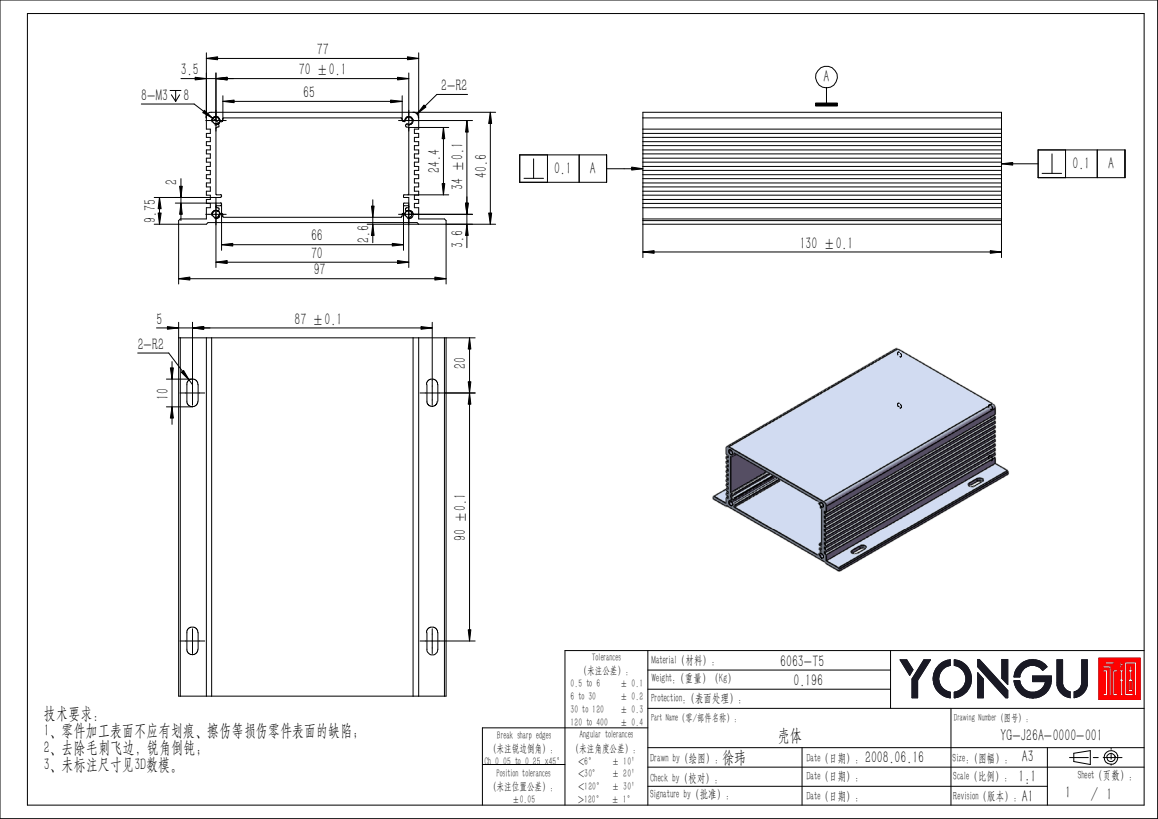
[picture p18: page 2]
Position tolerances; Signature by（批准）:; 技术要求： 1、零件加工表面不应有划痕、擦伤等损伤零件表面的缺陷； 2、去除毛刺飞边，锐角倒钝； 3、未标注尺寸见3D数模。

Material（材料）: Tolerances
（未注公差）：
Angular tolerances
（未注角度公差）：

Weight:（重量）（Kg）
Protection:（表面处理）：

Part Name（零/部件名称）: 壳体 | Drawing Number（图号）: YG-J26A-0000-001

Break sharp edges
（未注锐边倒角）：

Drawn by（绘图）: 徐玮 | 2008.06.16 | A3 Size:（图幅）：

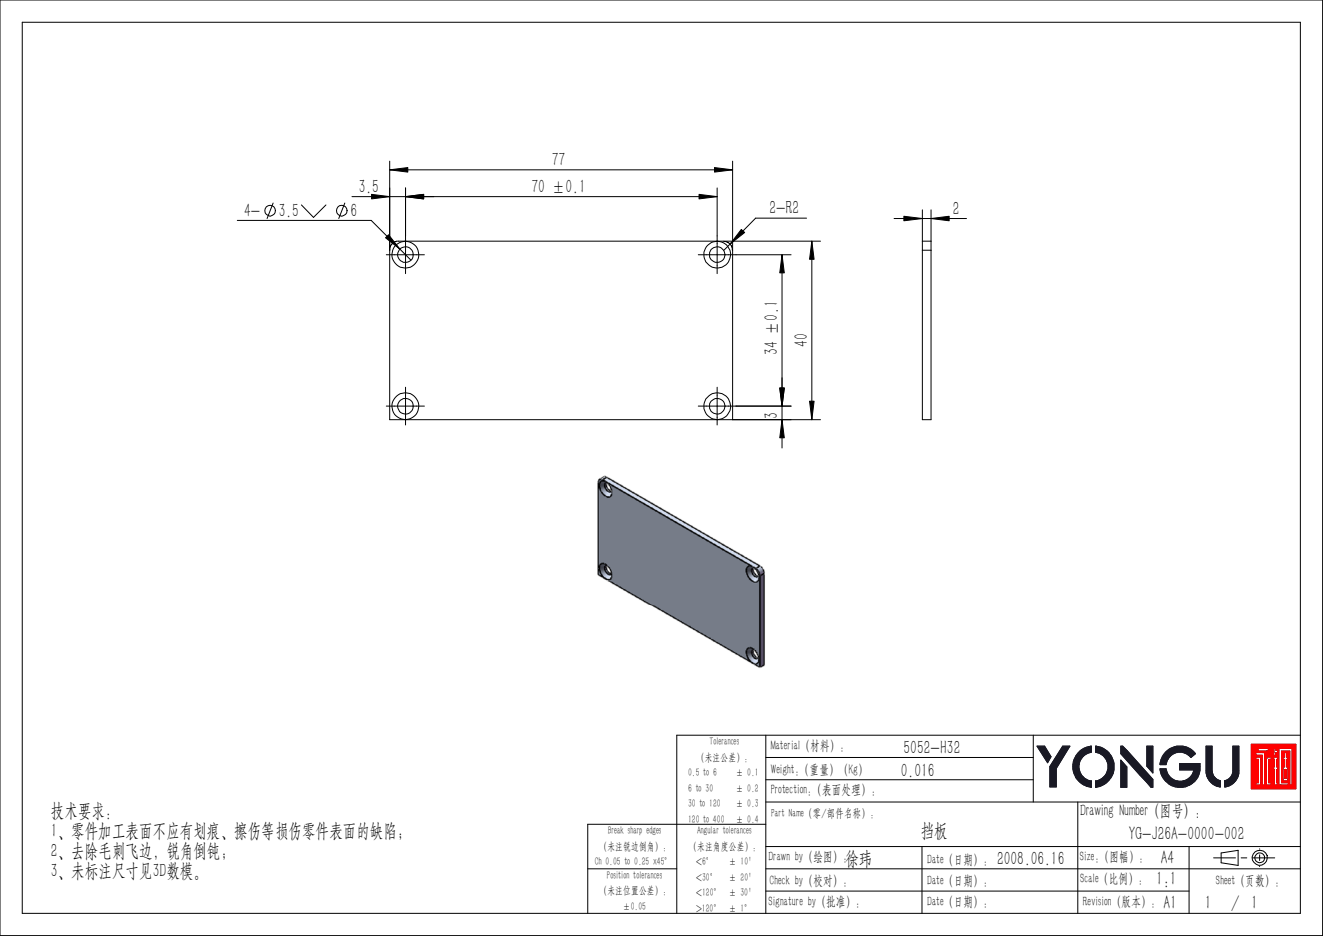
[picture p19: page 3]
Tolerances （未注公差）：; 技术要求： 1、零件加工表面不应有划痕、擦伤等损伤零件表面的缺陷； 2、去除毛刺飞边，锐角倒钝； 3、未标注尺寸见3D数模。

Material（材料）:
Weight:（重量）（Kg）
Protection:（表面处理）：

Part Name（零/部件名称）: 挡板 | Drawing Number（图号）: YG-J26A-0000-002

Break sharp edges （未注锐边倒角）： | Angular tolerances （未注角度公差）： ± 10' <30° ± 20' >120° ± 1° | Drawn by（绘图）: <6°

徐玮 | 2008.06.16 | Size:（图幅）： A4

Position tolerances ±0.05 | | | /

Signature by（批准）: | A1

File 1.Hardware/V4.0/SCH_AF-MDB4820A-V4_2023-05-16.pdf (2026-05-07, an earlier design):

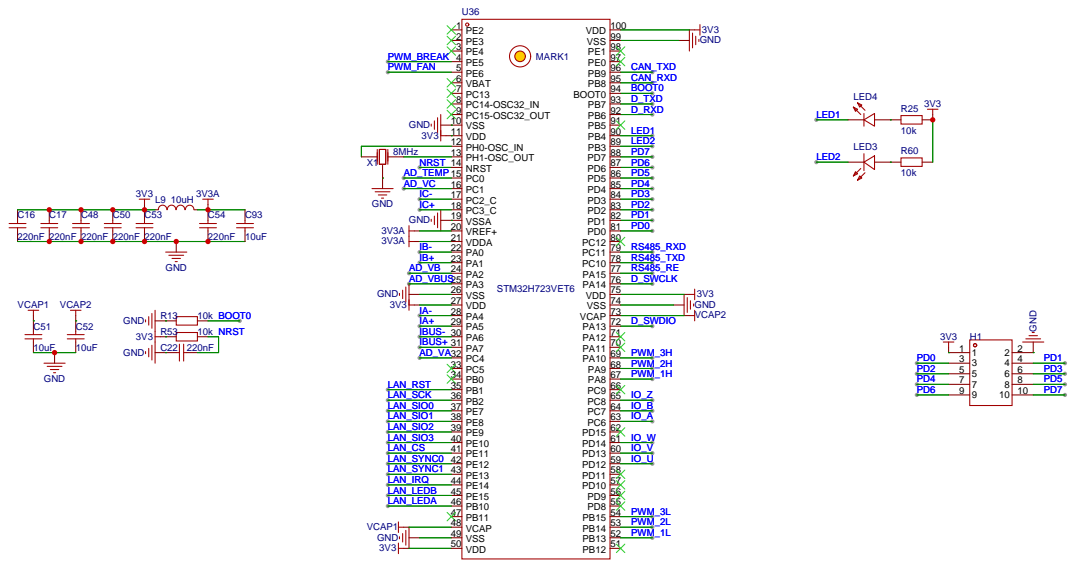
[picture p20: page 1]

PC7 64 PC8 65 PC9 66 PA8 67 PA9 68 PA10 69 PA11 70 PA12 71 PA13 72 VCAP 73 VSS 74 VDD 75 PA14 76 PA15 77 PC10 78 PC11 79 PC12 80 PD0 81 PD1 82 PD2 83 PD3 84 PD4 85 PD5 86 PD6 87 PD7 88 PB3 89 PB4 90 PB5 91 PB6 92 PB7 93 BOOT0 94 PB8 95 PB9 96 PE0 97 PE1 98 VSS 99 VDD 100

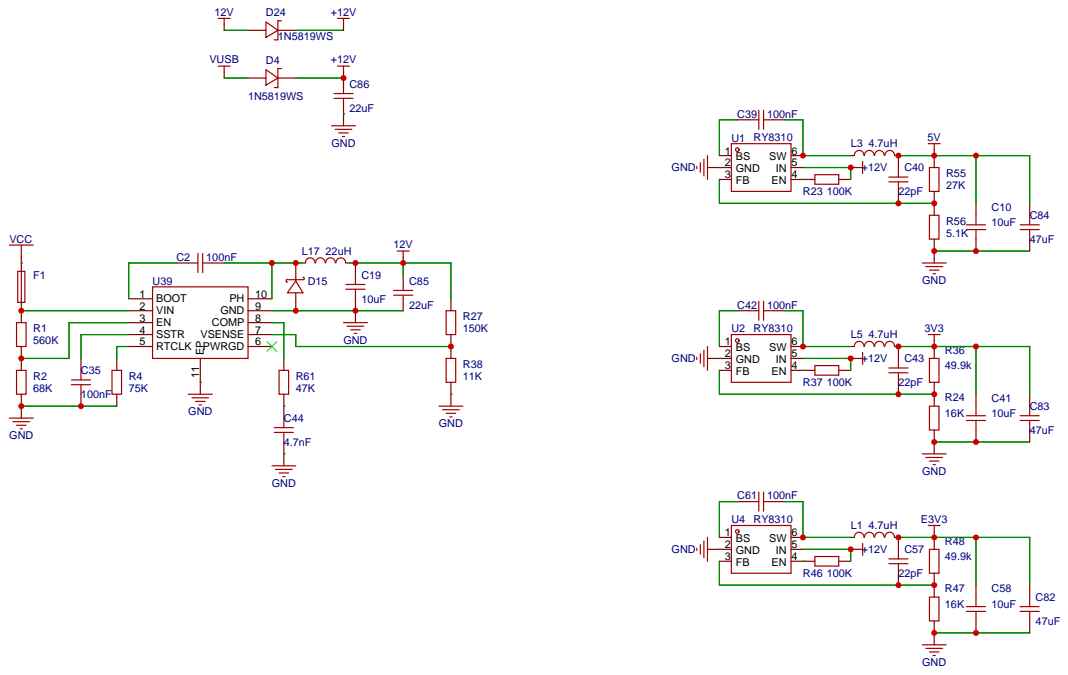
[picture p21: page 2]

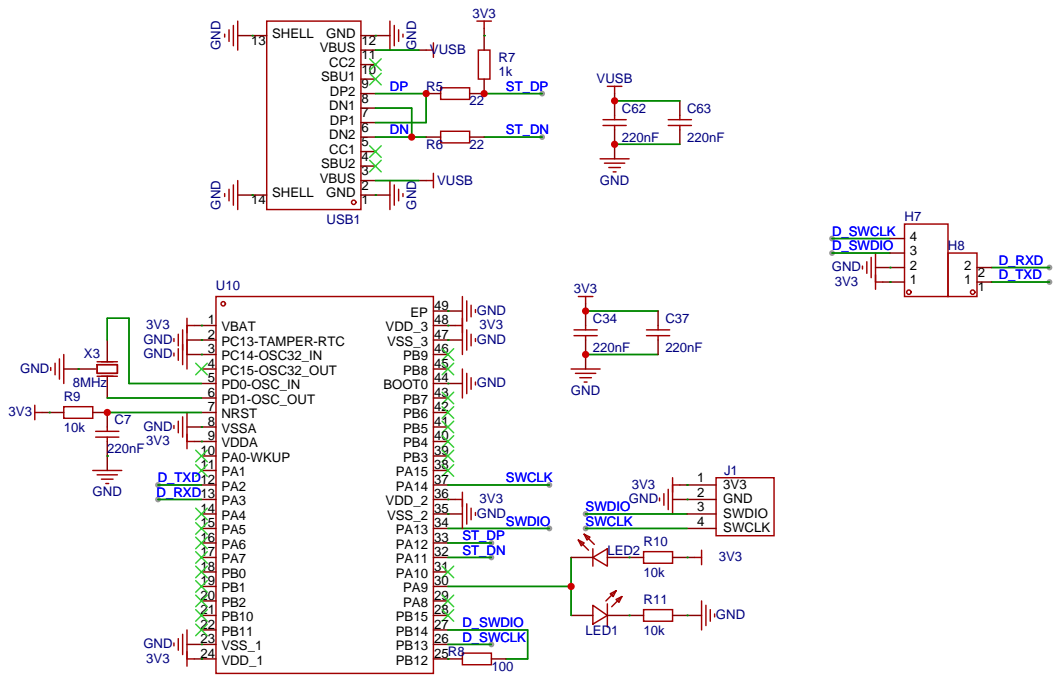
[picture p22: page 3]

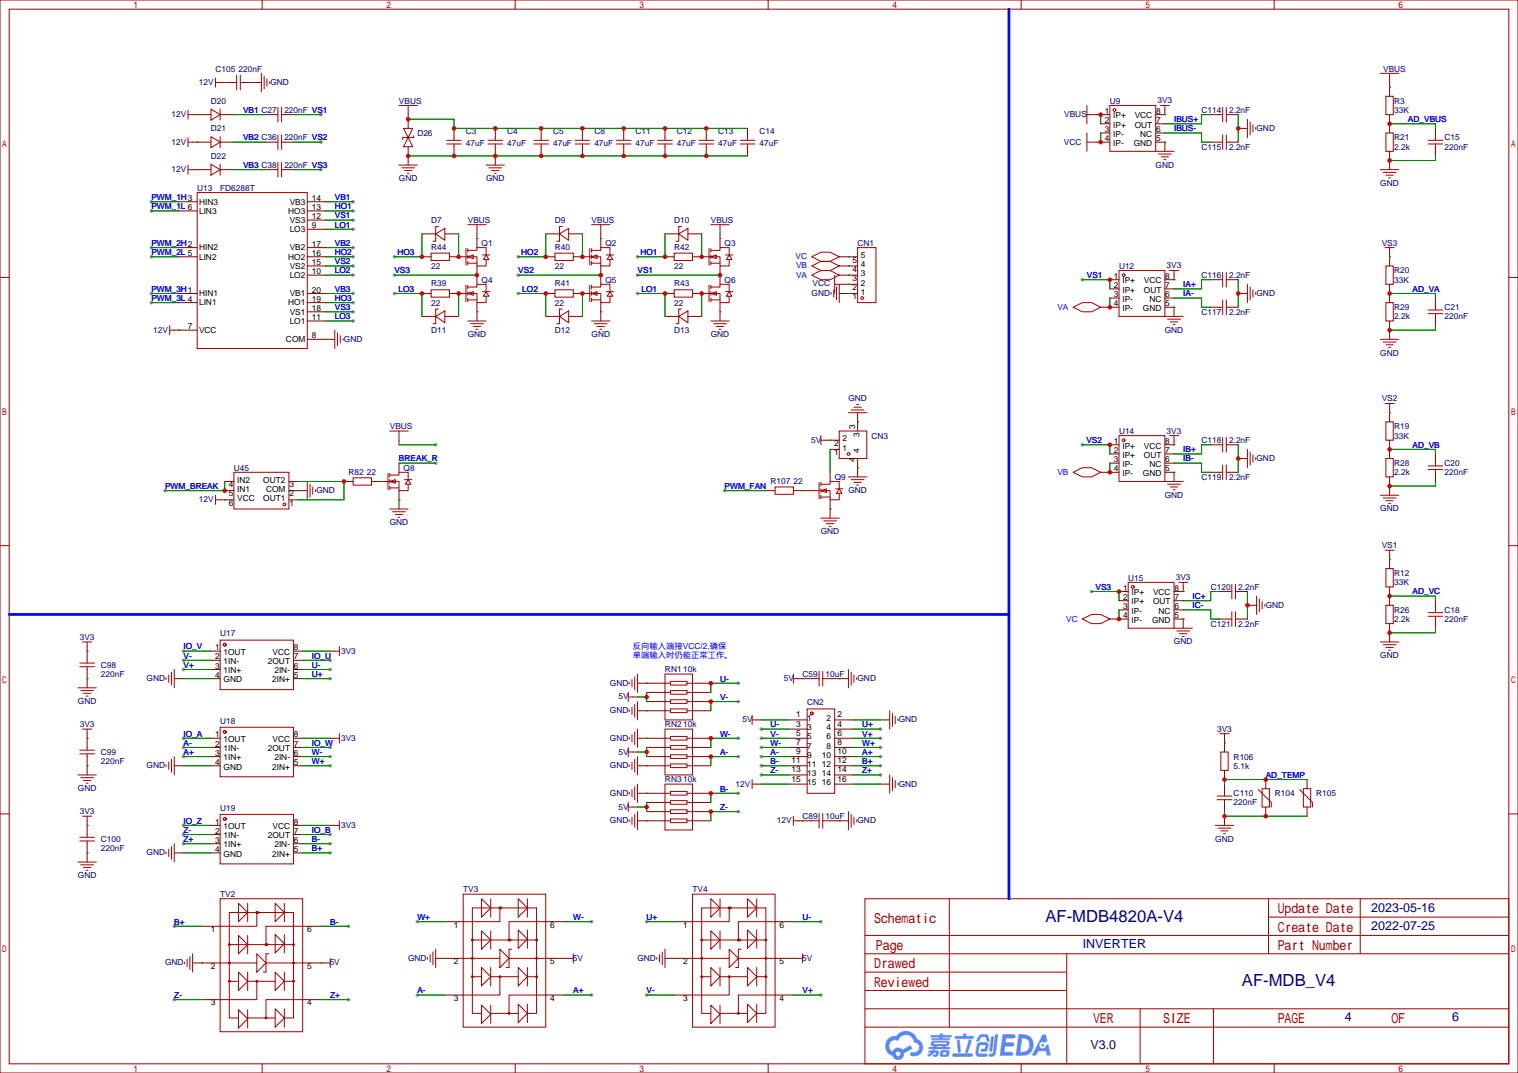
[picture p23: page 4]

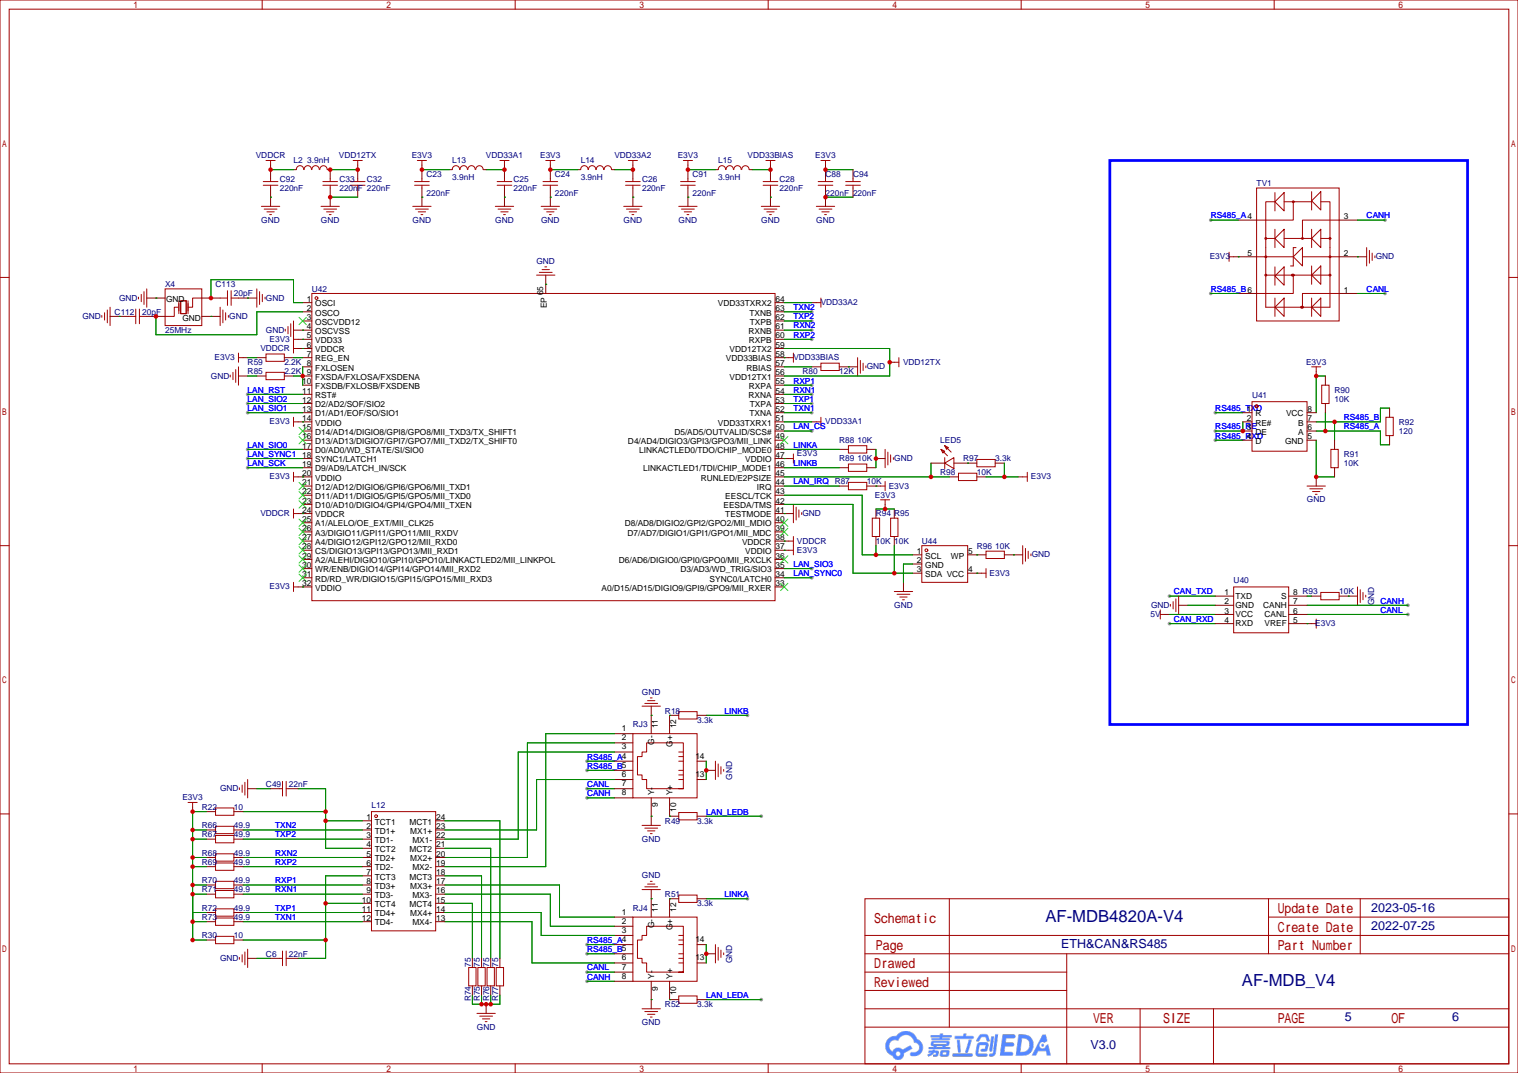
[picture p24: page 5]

### Reviewed

### Drawed

### Create Date Part Number

### Schematic

### Update Date

### Page

V3.0 | 嘉立创EDA

# AF-MDB_V4

| 2023-05-16

# 2022-10-11 AF-MDB4820A-V4

## SHELL

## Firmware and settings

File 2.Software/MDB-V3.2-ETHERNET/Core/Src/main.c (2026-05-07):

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
/* Includes ------------------------------------------------------------------*/
#include "main.h"
#include "adc.h"
#include "dma.h"
#include "lwip.h"
#include "tim.h"
#include "usart.h"
#include "gpio.h"

/* USER CODE BEGIN Includes */
#include <stdio.h>
#include <string.h>
#include <math.h>          // sin/cos 函数
#include "lwip/netif.h"
#include "lwip/stats.h"
#include "lwip/udp.h"      // UDP API
#include "lwip/pbuf.h"     // pbuf 管理
#include "lwip/ip4_addr.h" // IP 地址操作

// 重定向需要的头文件
#ifdef __GNUC__
#define PUTCHAR_PROTOTYPE int __io_putchar(int ch)
#else
#define PUTCHAR_PROTOTYPE int fputc(int ch, FILE *f)
#endif

/* USER CODE END Includes */


/* USER CODE BEGIN PV */
// ADC 数据缓冲区（DMA 循环模式,存储两次采样）
uint32_t adc1[8];  // ADC1 数据缓冲区（4 个通道 × 2 次采样 = 8）
uint32_t adc2[8];  // ADC2 数据缓冲区（4 个通道 × 2 次采样 = 8）

// SPWM 发生器变量
float spwm_angle = 0.0f;           // SPWM 相位角度 (0-360°)
const float spwm_freq = 50.0f;     // SPWM 频率 50Hz
float spwm_duty_min = 0.2f;        // 最小占空比 20%
float spwm_duty_max = 0.8f;        // 最大占空比 80%

// UDP 目标地址（动态获取）
ip_addr_t remote_ip;               // 远程 IP 地址
uint16_t remote_port = 0;          // 远程端口号
uint8_t remote_addr_valid = 0;     // 远程地址有效标志

// UDP 发送缓冲区（1KB）
#define UDP_BUFFER_SIZE 1024
uint8_t udp_tx_buffer[UDP_BUFFER_SIZE];
uint16_t udp_buffer_index = 0;     // 当前缓冲区写入位置
uint32_t last_send_tick = 0;       // 上次发送时间戳（单位: TIM1 中断次数）
/* USER CODE END PV */

void SystemClock_Config(void);
void PeriphCommonClock_Config(void);
static void MPU_Config(void);
/* USER CODE BEGIN 0 */

// 外部变量声明
extern ETH_HandleTypeDef heth;
extern struct netif gnetif;

// 串口重定向printf - 支持多种编译器
#ifdef __GNUC__
int __io_putchar(int ch)
{
  HAL_UART_Transmit(&huart1, (uint8_t *)&ch, 1, HAL_MAX_DELAY);
  return ch;
}

// 为GCC添加_write函数支持
int _write(int file, char *ptr, int len)
{
  int DataIdx;
  for (DataIdx = 0; DataIdx < len; DataIdx++)
  {
    __io_putchar(*ptr++);
  }
  return len;
}
#else
int fputc(int ch, FILE *f)
{
  HAL_UART_Transmit(&huart1, (uint8_t *)&ch, 1, HAL_MAX_DELAY);
  return ch;
}
#endif

//=============================================================================
// LAN9303 交换机寄存器诊断
//=============================================================================

/* LAN9303 虚拟交换寄存器读取 (通过 MDIO Clause 22) */
uint32_t LAN9303_Read_VirtualReg(uint16_t reg_addr)
{
  uint32_t reg_low, reg_high;
  
  // 写入要访问的虚拟寄存器地址到 VIRT_PHY_ADDR (0x10)
  HAL_ETH_WritePHYRegister(&heth, 0, 0x10, reg_addr);
  
  // 从 VIRT_PHY_DATA_LOW (0x11) 和 VIRT_PHY_DATA_HIGH (0x12) 读取32位数据
  HAL_ETH_ReadPHYRegister(&heth, 0, 0x11, &reg_low);
  HAL_ETH_ReadPHYRegister(&heth, 0, 0x12, &reg_high);
  
  return (reg_high << 16) | reg_low;
}

/* 检查 LAN9303 交换机状态 */
void Check_LAN9303_Switch(void)
{
  printf("\r\n========== LAN9303 交换机寄存器诊断 ==========\r\n");
  
  // 1. 读取芯片 ID
  uint32_t chip_id = LAN9303_Read_VirtualReg(0x50);
  printf("Chip ID: 0x%08lX (应为 0x00009303)\r\n", chip_id);
  
  // 2. 读取 Switch 配置
  uint32_t sw_cfg = LAN9303_Read_VirtualReg(0x0400);
  printf("Switch Config (0x0400): 0x%08lX\r\n", sw_cfg);
  printf("  - Switch Enable: %s\r\n", (sw_cfg & (1<<7)) ? "✅ 启用" : "❌ 禁用");
  
  // 3. 读取 Port 0 (CPU Port) 配置
  uint32_t port0_cfg = LAN9303_Read_VirtualReg(0x0410);
  printf("Port 0 (CPU) Config (0x0410): 0x%08lX\r\n", port0_cfg);
  printf("  - RX Enable: %s\r\n", (port0_cfg & (1<<2)) ? "✅" : "❌");
  printf("  - TX Enable: %s\r\n", (port0_cfg & (1<<1)) ? "✅" : "❌");
  
  // 4. 读取 Port 1 配置
  uint32_t port1_cfg = LAN9303_Read_VirtualReg(0x0420);
  printf("Port 1 Config (0x0420): 0x%08lX\r\n", port1_cfg);
  printf("  - RX Enable: %s\r\n", (port1_cfg & (1<<2)) ? "✅" : "❌");
  printf("  - TX Enable: %s\r\n", (port1_cfg & (1<<1)) ? "✅" : "❌");
  
  // 5. 读取 Port 2 配置
  uint32_t port2_cfg = LAN9303_Read_VirtualReg(0x0430);
  printf("Port 2 Config (0x0430): 0x%08lX\r\n", port2_cfg);
  printf("  - RX Enable: %s\r\n", (port2_cfg & (1<<2)) ? "✅" : "❌");
  printf("  - TX Enable: %s\r\n", (port2_cfg & (1<<1)) ? "✅" : "❌");
  
  // 6. 读取 VLAN 配置
  uint32_t vlan_port0 = LAN9303_Read_VirtualReg(0x0440);
  uint32_t vlan_port1 = LAN9303_Read_VirtualReg(0x0444);
  uint32_t vlan_port2 = LAN9303_Read_VirtualReg(0x0448);
  printf("VLAN Port Members:\r\n");
  printf("  Port 0: 0x%08lX (Bits: ", vlan_port0);
  if (vlan_port0 & (1<<0)) printf("P0 ");
  if (vlan_port0 & (1<<1)) printf("P1 ");
  if (vlan_port0 & (1<<2)) printf("P2");
  printf(")\r\n");
  printf("  Port 1: 0x%08lX (Bits: ", vlan_port1);
  if (vlan_port1 & (1<<0)) printf("P0 ");
  if (vlan_port1 & (1<<1)) printf("P1 ");
  if (vlan_port1 & (1<<2)) printf("P2");
  printf(")\r\n");
  printf("  Port 2: 0x%08lX (Bits: ", vlan_port2);
  if (vlan_port2 & (1<<0)) printf("P0 ");
  if (vlan_port2 & (1<<1)) printf("P1 ");
  if (vlan_port2 & (1<<2)) printf("P2");
  printf(")\r\n");
  
  // 检查关键问题：Port 0 能否向 Port 1/2 转发
  if (!(vlan_port0 & ((1<<1) | (1<<2)))) {
    printf("\r\n⚠️⚠️⚠️ 警告：Port 0 (CPU) 无法转发到 Port 1/2！\r\n");
    printf("这会导致 STM32 发送的数据无法到达外部网络。\r\n");
  } else {
    printf("\r\n✅ Port 0 可以转发到外部端口。\r\n");
  }
  
  printf("============================================\r\n");
}

//=============================================================================
// 以太网基本状态显示（精简版）
//=============================================================================

/* 显示网络基本信息 */
void Show_Network_Info(void)
{
  printf("\r\n========== 网络状态 ==========\r\n");
  printf("  IP: %s\r\n", ip4addr_ntoa(netif_ip4_addr(&gnetif)));
  printf("  Netmask: %s\r\n", ip4addr_ntoa(netif_ip4_netmask(&gnetif)));
  printf("  Gateway: %s\r\n", ip4addr_ntoa(netif_ip4_gw(&gnetif)));
  printf("  MAC: %02X:%02X:%02X:%02X:%02X:%02X\r\n",
         gnetif.hwaddr[0], gnetif.hwaddr[1], gnetif.hwaddr[2],
         gnetif.hwaddr[3], gnetif.hwaddr[4], gnetif.hwaddr[5]);
  printf("  Link: %s\r\n", netif_is_link_up(&gnetif) ? "UP" : "DOWN");
  printf("  Netif: %s\r\n", netif_is_up(&gnetif) ? "UP" : "DOWN");
  printf("  连接模式: 直连（无路由器）\r\n");
  printf("==============================\r\n");
}

//=============================================================================
// UDP Echo Server（UDP 回显服务器）
//=============================================================================

static struct udp_pcb *udp_echo_pcb = NULL;

/* UDP 接收回调函数（接收 PC 数据包，记录远程地址）*/
void udp_echo_recv_callback(void *arg, struct udp_pcb *pcb, struct pbuf *p,
                           const ip_addr_t *addr, u16_t port)
{
  if (p != NULL)
  {
    // 记录远程 IP 和端口（首次接收或更新）
    ip_addr_copy(remote_ip, *addr);
    remote_port = port;
    remote_addr_valid = 1;
    
    // 释放接收的数据包（不需要回显）
    pbuf_free(p);
  }
}

/* 初始化 UDP Echo Server */
void UDP_Echo_Server_Init(uint16_t port)
{
  err_t err;
  
  // 创建 UDP PCB（使用 IP_PROTO_UDP）
  udp_echo_pcb = udp_new_ip_type(IPADDR_TYPE_V4);
  
  if (udp_echo_pcb != NULL)
  {
    // 绑定到本地 IP 和指定端口（明确绑定到 gnetif 的 IP）
    err = udp_bind(udp_echo_pcb, netif_ip4_addr(&gnetif), port);
    
    if (err == ERR_OK)
    {
      // 设置接收回调函数
      udp_recv(udp_echo_pcb, udp_echo_recv_callback, NULL);
      printf("[UDP] Echo Server 已启动，监听端口 %d\r\n", port);
    }
    else
    {
      printf("[UDP] ❌ 绑定端口失败\r\n");
      udp_remove(udp_echo_pcb);
      udp_echo_pcb = NULL;
    }
  }
  else
  {
    printf("[UDP] ❌ 创建 PCB 失败\r\n");
  }
}

//=============================================================================
// 以太网状态显示（精简版 - 仅保留基本信息）
//=============================================================================

/* 显示 lwIP 统计信息（精简版）*/
void Show_lwIP_Stats(void)
{
  printf("\r\n[lwIP Stats]\r\n");
  
#if LWIP_STATS
  printf("  Link: RX=%u TX=%u | ", lwip_stats.link.recv, lwip_stats.link.xmit);
  printf("IP: RX=%u TX=%u | ", lwip_stats.ip.recv, lwip_stats.ip.xmit);
  printf("ICMP: RX=%u TX=%u | ", lwip_stats.icmp.recv, lwip_stats.icmp.xmit);
  printf("UDP: RX=%u TX=%u\r\n", lwip_stats.udp.recv, lwip_stats.udp.xmit);
#else
  printf("  Statistics disabled\r\n");
#endif
}

/* 旧的详细诊断函数 - 保留用于故障排查 */
void _OLD_Test_MDIO_ReadWrite(void)
{
  printf("\r\n========== MDIO 读写测试 ==========\r\n");
  printf("  LAN9303 PHY 地址映射:\r\n");
  printf("    PHY0 = 虚拟 CPU 端口 (STM32 连接)\r\n");
  printf("    PHY1 = Port1 外部端口\r\n");
  printf("    PHY2 = Port2 外部端口\r\n\r\n");
  
  // 扫描 PHY 地址 0-2
  for(uint32_t phy_addr = 0; phy_addr <= 2; phy_addr++)
  {
    uint32_t id1 = 0, id2 = 0, bmsr = 0, bmcr = 0;
    
    if(HAL_ETH_ReadPHYRegister(&heth, phy_addr, 2, &id1) == HAL_OK &&
       HAL_ETH_ReadPHYRegister(&heth, phy_addr, 3, &id2) == HAL_OK)
    {
      HAL_ETH_ReadPHYRegister(&heth, phy_addr, 0, &bmcr);
      HAL_ETH_ReadPHYRegister(&heth, phy_addr, 1, &bmsr);
      
      printf("  PHY[%lu]: ID1=0x%04lX ID2=0x%04lX BMCR=0x%04lX BMSR=0x%04lX\r\n",
             phy_addr, id1 & 0xFFFF, id2 & 0xFFFF, bmcr & 0xFFFF, bmsr & 0xFFFF);
      printf("         Link=%s, Speed=%s, Duplex=%s\r\n",
             (bmsr & (1<<2)) ? "UP" : "DOWN",
             (bmcr & (1<<13)) ? "100M" : "10M",
             (bmcr & (1<<8)) ? "Full" : "Half");
    }
  }
  
  // MDIO 写入测试 (测试 PHY0 的 BMCR 寄存器部分位)
  uint32_t original_bmcr = 0, modified_bmcr = 0;
  printf("\r\n  MDIO 写入测试 (PHY0):\r\n");
  
  // 读取原始 BMCR
  HAL_ETH_ReadPHYRegister(&heth, 0, 0, &original_bmcr);
  printf("    原始 BMCR = 0x%04lX\r\n", original_bmcr & 0xFFFF);
  
  // 测试写入 (切换 Loopback bit 15, 不影响通信)
  uint32_t test_val = original_bmcr ^ (1<<15);  // 翻转 Loopback 位
  HAL_ETH_WritePHYRegister(&heth, 0, 0, test_val);
  HAL_Delay(10);
  HAL_ETH_ReadPHYRegister(&heth, 0, 0, &modified_bmcr);
  printf("    写入后   = 0x%04lX\r\n", modified_bmcr & 0xFFFF);
  
  // 恢复原始值
  HAL_ETH_WritePHYRegister(&heth, 0, 0, original_bmcr);
  HAL_Delay(10);
  
  printf("    结果: %s\r\n", 
         (modified_bmcr == test_val) ? "✅ MDIO 读写正常" : "⚠️ 写入部分成功");
  
  printf("==========================================\r\n");
}

/* 2. ETH 寄存器状态检查 */
void Check_ETH_Registers(void)
{
  printf("\r\n========== ETH 寄存器状态 ==========\r\n");
  
  // MAC 配置寄存器
  uint32_t maccr = heth.Instance->MACCR;
  printf("  MACCR   = 0x%08lX\r\n", maccr);
  printf("    Speed=%s, Duplex=%s, Loopback=%s\r\n",
         (maccr & ETH_MACCR_FES) ? "100M" : "10M",
         (maccr & ETH_MACCR_DM) ? "Full" : "Half",
         (maccr & ETH_MACCR_LM) ? "ON" : "OFF");
  
  // DMA 状态寄存器
  printf("  DMACSR  = 0x%08lX\r\n", heth.Instance->DMACSR);
  printf("  DMADSR  = 0x%08lX ", heth.Instance->DMADSR);
  uint32_t dmadsr = heth.Instance->DMADSR;
  printf("(TxState=%lu, RxState=%lu)\r\n", 
         (dmadsr >> 12) & 0xF, (dmadsr >> 8) & 0xF);
  
  // DMA 中断状态
  printf("  DMAISR  = 0x%08lX\r\n", heth.Instance->DMAISR);
  
  // 描述符地址
  printf("  Tx Desc = 0x%08lX\r\n", (uint32_t)heth.Instance->DMACTDLAR);
  printf("  Rx Desc = 0x%08lX\r\n", (uint32_t)heth.Instance->DMACRDLAR);
  
  printf("==========================================\r\n");
}

/* 3. lwIP 网络接口状态 */
void Check_lwIP_Netif(void)
{
  printf("\r\n========== lwIP Netif 状态 ==========\r\n");
  
  // netif 基本状态
  printf("  netif.flags   = 0x%02X\r\n", gnetif.flags);
  printf("    UP=%d, Link=%d, Broadcast=%d\r\n",
         !!(gnetif.flags & NETIF_FLAG_UP),
         !!(gnetif.flags & NETIF_FLAG_LINK_UP),
         !!(gnetif.flags & NETIF_FLAG_BROADCAST));
  
  // IP 配置
  printf("  IP Address    = %u.%u.%u.%u\r\n",
         ip4_addr1(&gnetif.ip_addr), ip4_addr2(&gnetif.ip_addr),
         ip4_addr3(&gnetif.ip_addr), ip4_addr4(&gnetif.ip_addr));
  printf("  Netmask       = %u.%u.%u.%u\r\n",
         ip4_addr1(&gnetif.netmask), ip4_addr2(&gnetif.netmask),
         ip4_addr3(&gnetif.netmask), ip4_addr4(&gnetif.netmask));
  printf("  Gateway       = %u.%u.%u.%u\r\n",
         ip4_addr1(&gnetif.gw), ip4_addr2(&gnetif.gw),
         ip4_addr3(&gnetif.gw), ip4_addr4(&gnetif.gw));
  
  // MAC 地址
  printf("  MAC Address   = %02X:%02X:%02X:%02X:%02X:%02X\r\n",
         gnetif.hwaddr[0], gnetif.hwaddr[1], gnetif.hwaddr[2],
         gnetif.hwaddr[3], gnetif.hwaddr[4], gnetif.hwaddr[5]);
  
  printf("==========================================\r\n");
}

/* 4. lwIP 协议栈统计 */
void Check_lwIP_Stats(void)
{
  printf("\r\n========== lwIP 统计信息 ==========\r\n");
  
#if LWIP_STATS
  printf("  [Link] RX=%u TX=%u Drop=%u Err=%u\r\n",
         lwip_stats.link.recv, lwip_stats.link.xmit,
         lwip_stats.link.drop, lwip_stats.link.err);
  
  printf("  [IP4]  RX=%u TX=%u Drop=%u Err=%u\r\n",
         lwip_stats.ip.recv, lwip_stats.ip.xmit,
         lwip_stats.ip.drop, lwip_stats.ip.err);
  
  printf("  [ICMP] RX=%u TX=%u Drop=%u Err=%u\r\n",
         lwip_stats.icmp.recv, lwip_stats.icmp.xmit,
         lwip_stats.icmp.drop, lwip_stats.icmp.err);
  
  printf("  [UDP]  RX=%u TX=%u Drop=%u\r\n",
         lwip_stats.udp.recv, lwip_stats.udp.xmit, lwip_stats.udp.drop);
#else
  printf("  ⚠️ LWIP_STATS 未启用，无详细统计\r\n");
#endif
  
  printf("==========================================\r\n");
}

/* 5. RMII 数据收发测试 */
void Check_RMII_Activity(void)
{
  printf("\r\n========== RMII 数据活动检测 ==========\r\n");
  
  // 读取 DMA 计数器（如果硬件支持）
  // 注意：STM32H7 的 ETH 没有直接的包计数寄存器，需要通过 DMA 状态判断
  
  uint32_t dmadsr = heth.Instance->DMADSR;
  uint32_t tx_state = (dmadsr >> 12) & 0xF;
  uint32_t rx_state = (dmadsr >> 8) & 0xF;
  
  printf("  DMA Tx State: ");
  switch(tx_state) {
    case 0: printf("Stopped\r\n"); break;
    case 1: printf("Fetching Desc\r\n"); break;
    case 2: printf("Waiting for Status\r\n"); break;
    case 3: printf("Reading Data\r\n"); break;
    case 6: printf("Suspended\r\n"); break;
    case 7: printf("Closing Desc\r\n"); break;
    default: printf("Unknown (%lu)\r\n", tx_state); break;
  }
  
  printf("  DMA Rx State: ");
  switch(rx_state) {
    case 0: printf("Stopped\r\n"); break;
    case 1: printf("Fetching Desc\r\n"); break;
    case 3: printf("Waiting for Packet\r\n"); break;
    case 5: printf("Closing Desc\r\n"); break;
    case 7: printf("Transferring Data\r\n"); break;
    default: printf("Unknown (%lu)\r\n", rx_state); break;
  }
  
  // 检查是否有错误标志
  uint32_t dmaisr = heth.Instance->DMAISR;
  if(dmaisr & 0xFFFF) {
    printf("  ⚠️ DMA 中断标志: 0x%04lX\r\n", dmaisr & 0xFFFF);
  } else {
    printf("  ✅ 无 DMA 错误\r\n");
  }
  
  printf("==========================================\r\n");
}

/* 6. 主动发送 ARP 测试 TX 功能 */
void Test_ARP_Request(void)
{
  printf("\r\n========== ARP 请求测试 ==========\r\n");
  
  // 目标 IP: 192.168.1.1 (网关)
  ip4_addr_t target_ip;
  IP4_ADDR(&target_ip, 192, 168, 1, 1);
  
  printf("  发送 ARP 请求到 192.168.1.1...\r\n");
  
  // 发送 ARP 请求
  err_t result = etharp_request(&gnetif, &target_ip);
  
  if (result == ERR_OK) {
    printf("  ✅ ARP 请求已发送\r\n");
  } else {
    printf("  ❌ ARP 请求发送失败 (err=%d)\r\n", result);
  }
  
  printf("==========================================\r\n");
}

/* 完整诊断入口 */
void Run_Full_Diagnostics(void)
{
  printf("\r\n\r\n");
  printf("##################################################\r\n");
  printf("#         以太网完整诊断 - %lu ms           #\r\n", HAL_GetTick());
  printf("##################################################\r\n");
  
  Check_DMA_Descriptors();  // 首先检查 DMA 描述符
  Test_MDIO_ReadWrite();
  Check_ETH_Registers();
  Check_lwIP_Netif();
  Check_lwIP_Stats();
  Check_RMII_Activity();
  Test_ARP_Request();  // 测试 TX 发送
  
  printf("\r\n");
}

/* USER CODE END 0 */

/**
  * @brief  The application entry point.
  * @retval int
  */
int main(void)
{

  /* MPU Configuration--------------------------------------------------------*/
  MPU_Config();

  /* Enable the CPU Cache */

  /* Enable I-Cache---------------------------------------------------------*/
  SCB_EnableICache();

  /* Enable D-Cache---------------------------------------------------------*/
  SCB_EnableDCache();

  /* MCU Configuration--------------------------------------------------------*/

  /* Reset of all peripherals, Initializes the Flash interface and the Systick. */
  HAL_Init();

  /* Configure the system clock */
  SystemClock_Config();

  /* Configure the peripherals common clocks */
  PeriphCommonClock_Config();

  /* USER CODE BEGIN SysInit */
  __HAL_RCC_D2SRAM1_CLK_ENABLE();  // 使能 D2 SRAM1 时钟，用于 LWIP 内存
  /* USER CODE END SysInit */

  /* Initialize all configured peripherals */
  MX_GPIO_Init();
  MX_DMA_Init();
  MX_ADC1_Init();
  MX_TIM15_Init();
  MX_USART1_UART_Init();
  MX_ADC2_Init();
  MX_TIM1_Init();
  MX_TIM3_Init();
//  MX_LWIP_Init();
  /* USER CODE BEGIN 2 */
  
  /* ========== 外设启动初始化 ========== */
  
  /* GPIO 初始化延时 */
  HAL_Delay(100);
  
  /* UART 接收超时配置（可选，用于接收不定长数据） */
  HAL_UART_EnableReceiverTimeout(&huart1);
  HAL_UART_ReceiverTimeout_Config(&huart1, 0xFF);
  
  /* ADC 校准（建议在启动 DMA 之前执行） */
  HAL_ADCEx_Calibration_Start(&hadc1, ADC_CALIB_OFFSET, ADC_SINGLE_ENDED);
  HAL_ADCEx_Calibration_Start(&hadc2, ADC_CALIB_OFFSET, ADC_SINGLE_ENDED);
  
  /* 启动 ADC DMA 循环采集（每个通道采样 2 次，共 8 个数据） */
  HAL_ADC_Start_DMA(&hadc1, (uint32_t *)adc1, 8);  // ADC1: 4 个通道 × 2 次 = 8
  HAL_ADC_Start_DMA(&hadc2, (uint32_t *)adc2, 8);  // ADC2: 4 个通道 × 2 次 = 8

  /* 启动 TIM3 编码器模式 */
  HAL_TIM_Encoder_Start(&htim3, TIM_CHANNEL_ALL);
  
  /* 启动 TIM3 通道 3 输入捕获中断 */
  HAL_TIM_IC_Start_IT(&htim3, TIM_CHANNEL_3);
  
  /* 启动 TIM1 PWM 输出（3 个通道） */
  HAL_TIM_PWM_Start(&htim1, TIM_CHANNEL_1);
  HAL_TIM_PWM_Start(&htim1, TIM_CHANNEL_2);
  HAL_TIM_PWM_Start(&htim1, TIM_CHANNEL_3);
  
  /* 启动 TIM1 互补输出（3 个通道） */
  HAL_TIMEx_PWMN_Start(&htim1, TIM_CHANNEL_1);
  HAL_TIMEx_PWMN_Start(&htim1, TIM_CHANNEL_2);
  HAL_TIMEx_PWMN_Start(&htim1, TIM_CHANNEL_3);
  
  /* 启动 TIM1 基础定时器中断 */
  HAL_TIM_Base_Start_IT(&htim1);
  
  /* ========== 以太网模块初始化 ========== */
  
  printf("\r\n========== 以太网初始化 ==========%s\r\n", "");
  
  /* 启动 TIM15 PWM 输出（为 LAN9303 提供 25MHz 时钟） */
  HAL_TIM_PWM_Start(&htim15, TIM_CHANNEL_1);
  HAL_Delay(100);


  /* 初始化 LWIP (包含以太网 HAL 初始化) */
  MX_LWIP_Init();
  
  SCB_CleanInvalidateDCache();
  /* 复位LAN9303并等待 */
  HAL_GPIO_WritePin(GPIOC, GPIO_PIN_3, GPIO_PIN_RESET);
  HAL_Delay(10);
  HAL_GPIO_WritePin(GPIOC, GPIO_PIN_3, GPIO_PIN_SET);
  HAL_Delay(100);
  printf("\r\n========== 初始化完成 ==========\r\n");
  
  /* 等待链路稳定 */
  HAL_Delay(500);
  
  /* 显示网络信息 */
  Show_Network_Info();
  
  /* 检查 LAN9303 交换机寄存器 */
  HAL_Delay(500); // 等待交换机稳定
  Check_LAN9303_Switch();
  
  /* 启动 UDP Echo Server (端口 7) */
  UDP_Echo_Server_Init(7);
  
  printf("\r\n系统就绪，等待 UDP 数据...\r\n\r\n");

  /* USER CODE END 2 */

  /* Infinite loop */
  /* USER CODE BEGIN WHILE */
  
  while (1)
  {
    /* 处理 lwIP 协议栈（高速模式：无延迟，无打印）*/
    MX_LWIP_Process();
    /* USER CODE END WHILE */

    /* USER CODE BEGIN 3 */
    
    /* 高速 UDP 优化：
     * - 移除所有周期性打印（避免串口阻塞）
     * - 移除 HAL_Delay(1)（避免不必要的延迟）
     * - 主循环专注于 lwIP 处理，最大化吞吐量
     */
  }
  /* USER CODE END 3 */
}

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
/* USER CODE BEGIN 4 */

//=============================================================================
// TIM1 更新中断回调函数 - 10kHz 中断频率
// - 生成三相 50Hz SPWM 波形（相位差 120°）
// - 采集 ADC 数据并通过 UDP 发送
//=============================================================================

// 数学常量
#define PI 3.14159265358979323846f
#define DEG_TO_RAD (PI / 180.0f)

// TIM1 参数（中心对齐模式：向上和向下都触发中断）
#define TIM1_PERIOD 9999                    // TIM1 ARR 值
#define TIM1_FREQ 20000.0f                  // TIM1 中断频率 20kHz（中心对齐模式 = 200MHz / 10000）
#define SPWM_FREQ 50.0f                     // SPWM 输出频率 50Hz
#define ANGLE_INCREMENT (360.0f * SPWM_FREQ / TIM1_FREQ)  // 每次中断角度增量 = 0.9°

// UDP 发送控制（1ms 或缓冲区满时发送）
#define UDP_SEND_TIMEOUT 20                 // 超时时间 20 次中断 = 1ms（20kHz → 0.05ms/次）
static uint16_t adc_sample_counter = 0;     // ADC 采样计数器（每 20 次中断采样一次）

// ADC 数据结构（用于 UDP 发送）
typedef struct {
  uint16_t adc1_ch[4];  // ADC1 的 4 个通道平均值
  uint16_t adc2_ch[4];  // ADC2 的 4 个通道平均值
} ADC_Data_t;

/* UDP 发送函数（缓冲区满或超时时调用）*/
void UDP_Send_Buffer(void)
{
  if (!remote_addr_valid || udp_buffer_index == 0) {
    return;  // 无有效地址或缓冲区为空，不发送
  }
  
  // 如果数据不足 1KB，用 0 补齐
  if (udp_buffer_index < UDP_BUFFER_SIZE) {
    memset(&udp_tx_buffer[udp_buffer_index], 0, UDP_BUFFER_SIZE - udp_buffer_index);
  }
  
  // 通过 UDP 发送整个缓冲区（1KB）
  struct pbuf *p = pbuf_alloc(PBUF_TRANSPORT, UDP_BUFFER_SIZE, PBUF_RAM);
  if (p != NULL)
  {
    memcpy(p->payload, udp_tx_buffer, UDP_BUFFER_SIZE);
    udp_sendto(udp_echo_pcb, p, &remote_ip, remote_port);
    pbuf_free(p);
  }
  
  // 重置缓冲区
  udp_buffer_index = 0;
  last_send_tick = 0;
}
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

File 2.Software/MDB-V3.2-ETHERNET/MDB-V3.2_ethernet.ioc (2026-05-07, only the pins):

Mcu.UserName=STM32H750VBTx
PA0.GPIO_Label=AD_VC
PA0.Signal=ADC1_INP16
PA1.Signal=ETH_REF_CLK
PA2.Signal=ETH_MDIO
PA3.GPIO_Label=AD_VB
PA3.Signal=ADCx_INP15
PA4.GPIO_Label=AD_VA
PA4.Signal=ADCx_INP18
PA5.GPIO_Label=AD_VBUS
PA5.Signal=ADCx_INP19
PA6.GPIO_Label=AD_IB
PA6.Signal=ADCx_INP3
PA7.Signal=ETH_CRS_DV
PB0.GPIO_Label=AD_IA
PB0.Signal=ADCx_INP9
PB1.GPIO_Label=AD_IBUS
PB1.Signal=ADCx_INP5
PB11.Signal=ETH_TX_EN
PB12.Signal=ETH_TXD0
PB13.Signal=ETH_TXD1
PB6.Signal=USART1_TX
PB7.Signal=USART1_RX
PB8.Signal=FDCAN1_RX
PB9.Signal=FDCAN1_TX
PC0.GPIO_Label=AD_IC
PC0.Signal=ADCx_INP10
PC1.Signal=ETH_MDC
PC2_C.GPIO_Label=LAN_IRQ
PC2_C.Signal=GPIO_Input
PC3_C.GPIO_Label=LAN_NRST
PC3_C.Signal=GPIO_Output
PC4.Signal=ETH_RXD0
PC5.Signal=ETH_RXD1
PC6.GPIO_Label=ENC_A
PC6.Signal=S_TIM3_CH1
PC7.GPIO_Label=ENC_B
PC7.Signal=S_TIM3_CH2
PC8.Signal=S_TIM3_CH3
PD0.GPIO_Label=D0
PD0.Signal=GPIO_Output
PD1.GPIO_Label=D1
PD1.Signal=GPIO_Output
PD10.GPIO_Label=HALL_W
PD10.Signal=GPIO_Input
PD2.GPIO_Label=D2
PD2.Signal=GPIO_Output
PD3.GPIO_Label=D3
PD3.Signal=GPIO_Output
PD4.GPIO_Label=D4
PD4.Signal=GPIO_Output
PD5.GPIO_Label=D5
PD5.Signal=GPIO_Output
PD6.GPIO_Label=D6
PD6.Signal=GPIO_Output
PD7.GPIO_Label=D7
PD7.Signal=GPIO_Output
PD8.GPIO_Label=HALL_U
PD8.Signal=GPIO_Input
PD9.GPIO_Label=HALL_V
PD9.Signal=GPIO_Input
PE10.Signal=TIM1_CH2N
PE11.Signal=S_TIM1_CH2
PE12.Signal=TIM1_CH3N
PE13.Signal=S_TIM1_CH3
PE4.GPIO_Label=LED_BLUE
PE4.Signal=GPIO_Output
PE5.Signal=S_TIM15_CH1
PE6.GPIO_Label=LED_RED
PE6.Signal=GPIO_Output
PE8.Signal=TIM1_CH1N
PE9.Signal=S_TIM1_CH1

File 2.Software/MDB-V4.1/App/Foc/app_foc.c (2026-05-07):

/*
 * @Author: xjf
 * @Date: 2023-03-13 17:21:40
 * @LastEditTime: 2023-03-14 00:21:19
 * @LastEditors: xjf
 * @Description: FOC控制顶层文件，定义输入输出接口，调用 simulink 文件。
 */
#include "app_foc.h"
#include "tim.h"
#include "adc.h"
#include "dac.h"

RT_MODEL rtM;
ExtU rtU;
ExtY rtY;

void foc_control(void)
{
	int16_t pwm_a, pwm_b, pwm_c;

	/* 设置输入变量 */
	rtU.AD_Vbus = (adc3[0]+adc3[2])*4; //ADC3使用的12位模式，
	rtU.ADC_Iabc[0] = -adc2[0]-adc2[3];
	rtU.ADC_Iabc[1] = -adc2[1]-adc2[4];
	rtU.ADC_Iabc[2] = -adc2[2]-adc2[5];
	rtU.Enable = 1;
	rtU.Encoder = __HAL_TIM_GET_COUNTER(&htim3);
	rtU.Hall[0] = HAL_GPIO_ReadPin(HALL_U_GPIO_Port, HALL_U_Pin);
	rtU.Hall[1] = HAL_GPIO_ReadPin(HALL_V_GPIO_Port, HALL_V_Pin);
	rtU.Hall[2] = HAL_GPIO_ReadPin(HALL_W_GPIO_Port, HALL_W_Pin);
	rtU.Spd_set = SL_rec.data[1]/32.0+SL_rec.data[2]/32.0*sin(2*3.1415926*SL_rec.data[3]*(step%20000)/20000);

	/* 调用simulink算法 */
	FOC_step(&rtM, &rtU, &rtY);

	/* 设置输出变量 */
	if(rtY.PowerOn)
	{
		pwm_a = rtY.Duty[0];
		pwm_b = rtY.Duty[1];
		pwm_c = rtY.Duty[2];
	}
	else
	{
		pwm_a = 5000;
		pwm_b = 5000;
		pwm_c = 5000;
	}
	/* 高频注入 */
	float hf;
	hf = 2*3.1415926*(step%20)/20;
	pwm_a +=  SL_rec.data[4]*cos(hf);
	pwm_b +=  SL_rec.data[4]*cos(hf+2*3.1415926/3);
	pwm_c +=  SL_rec.data[4]*cos(hf-2*3.1415926/3);

	pwm_a = pwm_a>10000?10000:pwm_a;
	pwm_b = pwm_b>10000?10000:pwm_b;
	pwm_c = pwm_c>10000?10000:pwm_c;
	pwm_a = pwm_a<0?0:pwm_a;
	pwm_b = pwm_b<0?0:pwm_b;
	pwm_c = pwm_c<0?0:pwm_c;

	__HAL_TIM_SET_COMPARE(&htim1, TIM_CHANNEL_1,  pwm_a);
	__HAL_TIM_SET_COMPARE(&htim1, TIM_CHANNEL_2,  pwm_b);
	__HAL_TIM_SET_COMPARE(&htim1, TIM_CHANNEL_3,  pwm_c);
	HAL_DAC_SetValue(&hdac1, DAC_CHANNEL_2, DAC_ALIGN_12B_R, 2048+rtY.Sensor_Speed_m*4096/314.15/3.3);

}

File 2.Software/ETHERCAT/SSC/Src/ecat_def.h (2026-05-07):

/*
* This source file is part of the EtherCAT Slave Stack Code licensed by Beckhoff Automation GmbH & Co KG, 33415 Verl, Germany.
* The corresponding license agreement applies. This hint shall not be removed.
*/


/*-----------------------------------------------------------------------------------------
------	
------	ecat_def.h
------  SSC version : 5.12
-----------------------------------------------------------------------------------------*/

#ifndef _ECATDEF_H_
#define _ECATDEF_H_

/*-----------------------------------------------------------------------------------------
------	
------	Includes
------ 
-----------------------------------------------------------------------------------------*/
#include <stdlib.h>
#include <string.h>

/*-----------------------------------------------------------------------------------------
------	
------	Slave Sample Code Configuration Defines
------	
-----------------------------------------------------------------------------------------*/
#define SSC_VERSION_MAJOR 5
#define SSC_VERSION_MINOR 12


/** 
EL9800_HW: Shall be set if the Slave code is executed on the PIC mounted on the EL9800 EtherCAT Evaluation Board.<br>
(if the MCI interface provided by EL9800 board should be used MCI_HW shall be set and this define shall be reset).<br>
This settings should also be enabled if the ESC is connected via a serial interface and no specific hardware access files are avilable yet.<br>
NOTE: The PDI type needs also to be configured in the "ESC_CONFIG_DATA". */
#ifndef EL9800_HW
#define EL9800_HW                                 1 //This define was already evaluated by ET9300 Project Handler(V. 1.4.0.0)!
#endif

/** 
MCI_HW: Shall be set if the MCI of the ESC is connected.<br>
This settings should also be enabled if the ESC is connected via a parallel interface and no specific hardware access files are avilable yet.<br>
NOTE: The PDI type needs also to be configured in the "ESC_CONFIG_DATA". */
#ifndef MCI_HW
#define MCI_HW                                    0 //This define was already evaluated by ET9300 Project Handler(V. 1.4.0.0)!
#endif

/** 
FC1100_HW: Shall be set if the EtherCAT slave controller is located on an FC1100 PCI card.<br>
NOTE: The PDI type needs also to be configured in the "ESC_CONFIG_DATA". */
#ifndef FC1100_HW
#define FC1100_HW                                 0 //This define was already evaluated by ET9300 Project Handler(V. 1.4.0.0)!
#endif

/** 
TIESC_HW: Temporary define to support TI ICE/IDK development board (Shall be set if the Slave code shall executed on an AM335X ICE/IDK Evaluation Board<br>
from Texas Instruments) */
#ifndef TIESC_HW
#define TIESC_HW                                  0 //This define was already evaluated by ET9300 Project Handler(V. 1.4.0.0)!
#endif

/** 
CONTROLLER_16BIT: Shall be set if the host controller is a 16Bit architecture */
#ifndef CONTROLLER_16BIT
#define CONTROLLER_16BIT                          1 //This define was already evaluated by ET9300 Project Handler(V. 1.4.0.0)!
#endif

/** 
CONTROLLER_32BIT: Shall be set if the host controller is a 32Bit architecture */
#ifndef CONTROLLER_32BIT
#define CONTROLLER_32BIT                          0 //This define was already evaluated by ET9300 Project Handler(V. 1.4.0.0)!
#endif

/** 
_PIC18: Microchip PIC18F452 Specific Code <br>
This processor is mounted on the Beckhoff Slave Evaluation Board (Hardware version up to EL9800_2). */
#ifndef _PIC18
#define _PIC18                                    0 //This define was already evaluated by ET9300 Project Handler(V. 1.4.0.0)!
#endif

/** 
_PIC24: Microchip PIC24HJ128GP306 Specific Code <br>
This processor is mounted on the Beckhoff Slave Evaluation Board (Hardware version up to EL9800_4A). */
#ifndef _PIC24
#define _PIC24                                    1 //This define was already evaluated by ET9300 Project Handler(V. 1.4.0.0)!
#endif

/** 
ESC_16BIT_ACCESS: If the microcontroller only supports 16Bit access to the ESC. */
#ifndef ESC_16BIT_ACCESS
#define ESC_16BIT_ACCESS                          1 //This define was already evaluated by ET9300 Project Handler(V. 1.4.0.0)!
#endif

/** 
ESC_32BIT_ACCESS: If the microcontroller only supports 32Bit access to the ESC. */
#ifndef ESC_32BIT_ACCESS
#define ESC_32BIT_ACCESS                          0 //This define was already evaluated by ET9300 Project Handler(V. 1.4.0.0)!
#endif

/** 
MBX_16BIT_ACCESS: If the microcontroller only supports 16Bit access to local mailbox memory(access to ESC DPRAM is controlled by "ESC_16BIT_ACCESS"). If reset 8Bit access is used. */
#ifndef MBX_16BIT_ACCESS
#define MBX_16BIT_ACCESS                          1 //This define was already evaluated by ET9300 Project Handler(V. 1.4.0.0)!
#endif
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

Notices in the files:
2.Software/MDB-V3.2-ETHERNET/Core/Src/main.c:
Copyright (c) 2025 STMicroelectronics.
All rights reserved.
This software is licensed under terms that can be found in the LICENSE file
